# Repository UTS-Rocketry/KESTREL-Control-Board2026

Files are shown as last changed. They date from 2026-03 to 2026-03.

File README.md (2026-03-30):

# CAS Interface Board 2026



Control Actuation System (CAS) Interface Board for the UTS Rocketry avionics stack.

This board provides closed-loop control for the airbrake and parafoil control systems, along with sensor interfaces and onboard data logging. The design is based on the STM32F405RGT6 microcontroller and integrates inertial sensing, actuator control, and non-volatile storage.

The CAS board is intended to operate as part of the UTS Rocketry flight avionics architecture.

---

## Overview

The CAS Interface Board is responsible for:

- Airbrake deployment control
- Roll stabilisation control
- Sensor acquisition
- Data logging
- Actuator interfacing

Closed-loop control is performed onboard using IMU, barometric sensor, and GPS measurements.

---

## Hardware

### Microcontroller

STM32F405RGT6

- ARM Cortex-M4F
- 168 MHz
- Hardware floating point
- 1 MB Flash
- 192 KB RAM

---

### Sensors

#### IMU

LSM6DS3TR-C

Interface:

- SPI (4-wire)

Signals:

- SCK
- MOSI
- MISO
- CS
- DRDY Interrupt

Power:

- 3.3 V

---

#### Barometer

Interface:

- I2C

Signals:

- SCL
- SDA

Power:

- 3.3 V

---

### Storage

#### MicroSD Card

Interface:

- SPI

Signals:

- SCK
- MOSI
- MISO
- CS

Purpose:

- Flight data logging

---

### Actuator Interfaces

#### Servo Outputs

- Airbrake Servo
- Roll Control Servo

Control Method:

- Timer PWM outputs

Power:

- Dedicated 5 V servo rail

Signal Voltage:

- 3.3 V logic

---

## Control System

### Airbrake Control

The CAS system predicts apogee using altitude and velocity estimates derived from sensor measurements.

Airbrake deployment is adjusted to reach the target apogee.

Inputs:

- Barometer altitude
- Estimated vertical velocity

Outputs:

- Airbrake servo PWM

## Firmware

Development tools:

- STM32CubeMX
- STM32CubeIDE
- ST-Link

Features:

- SPI IMU driver
- I2C barometer driver
- PWM servo control
- SD card logging
- Flash logging
- Interrupt-driven sensor acquisition

---

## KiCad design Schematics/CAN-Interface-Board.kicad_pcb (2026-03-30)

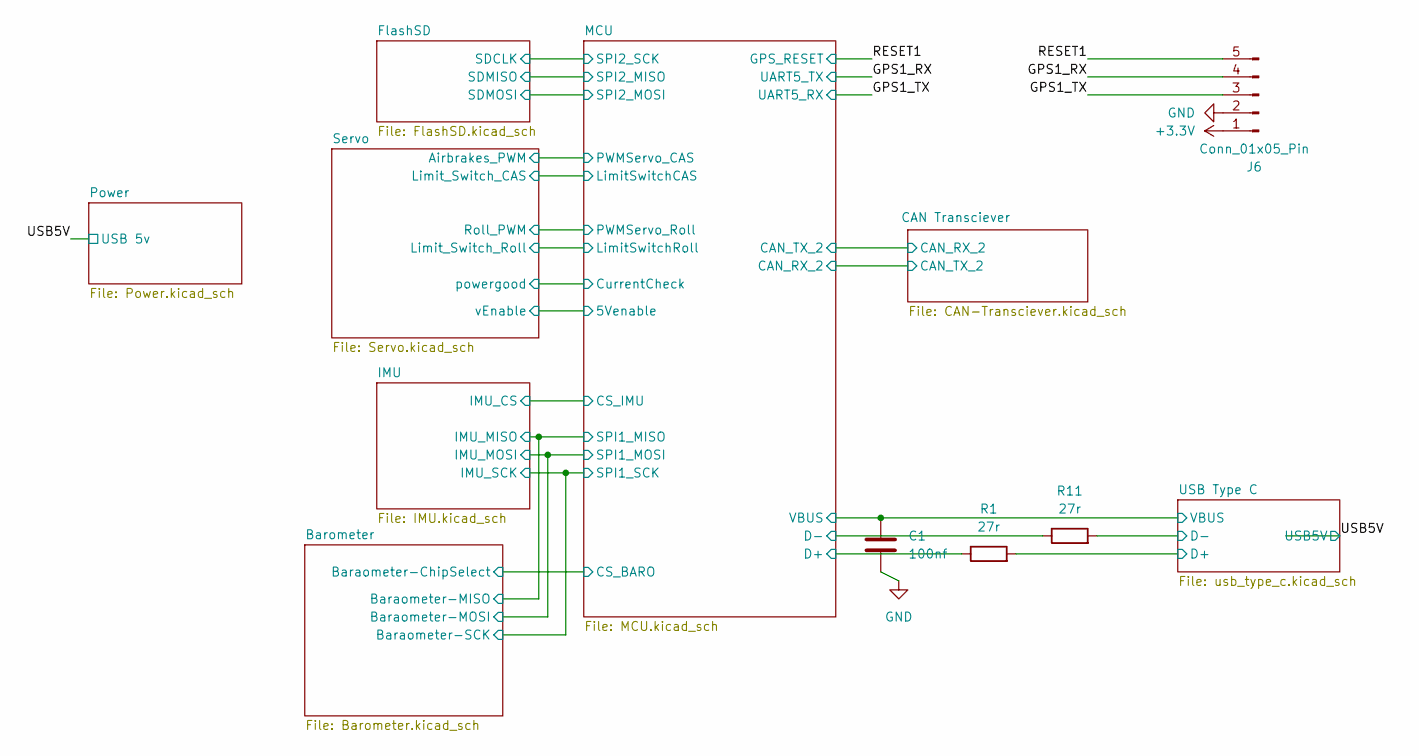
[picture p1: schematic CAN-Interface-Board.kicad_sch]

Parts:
C1: 100nf; C_0805_2012Metric_Pad1.18x1.45mm_HandSolder; LCSC C49678
J6: Conn_01x05_Pin; JST_XH_B5B-XH-A_1x05_P2.50mm_Vertical; LCSC C157991
R1, R11: 27r; R_0805_2012Metric_Pad1.20x1.40mm_HandSolder; LCSC C17594

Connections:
+3.3V: J6.1; also elsewhere on the board
/GPS1_RX: J6.4; also elsewhere on the board
/GPS1_TX: J6.3; also elsewhere on the board
/MCU/D+: R1.1; also elsewhere on the board
/MCU/D-: R11.1; also elsewhere on the board
/RESET1: J6.5; also elsewhere on the board
/USB5V: C1.1; also elsewhere on the board
/USB Type C/D+: R1.2; also elsewhere on the board
/USB Type C/D-: R11.2; also elsewhere on the board
GND: C1.2, J6.2; also elsewhere on the board

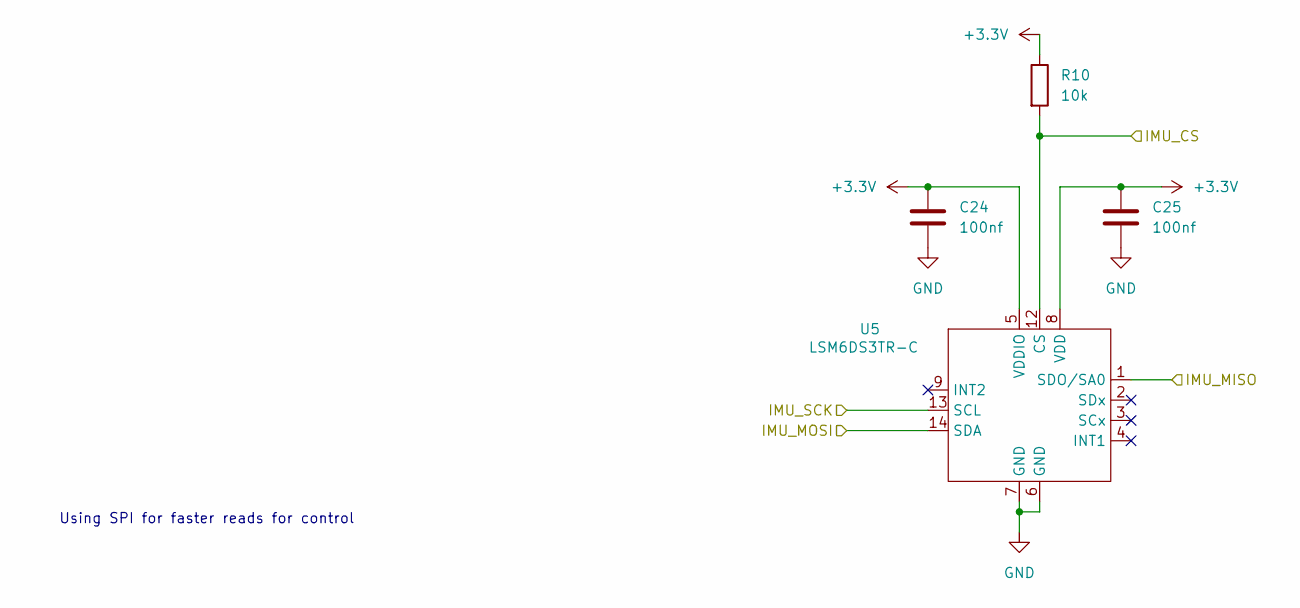
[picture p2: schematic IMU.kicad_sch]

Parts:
C24, C25: 100nf; C_0805_2012Metric_Pad1.18x1.45mm_HandSolder; LCSC Part C49678
R10: 10k; R_0805_2012Metric_Pad1.20x1.40mm_HandSolder; LCSC C84376
U5: LSM6DS3TR-C; LGA-14-2.5X3MM; LCSC Part C967633

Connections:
+3.3V: C24.1, C25.1, R10.1, U5.5 (VDDIO), U5.8 (VDD); also elsewhere on the board
/Barometer/Baraometer-MISO: U5.1 (SDO/SA0); also elsewhere on the board
/Barometer/Baraometer-MOSI: U5.14 (SDA); also elsewhere on the board
/Barometer/Baraometer-SCK: U5.13 (SCL); also elsewhere on the board
/IMU/IMU_CS: R10.2, U5.12 (CS); also elsewhere on the board
GND: C24.2, C25.2, U5.6 (GND), U5.7 (GND); also elsewhere on the board

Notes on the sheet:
Using SPI for faster reads for control

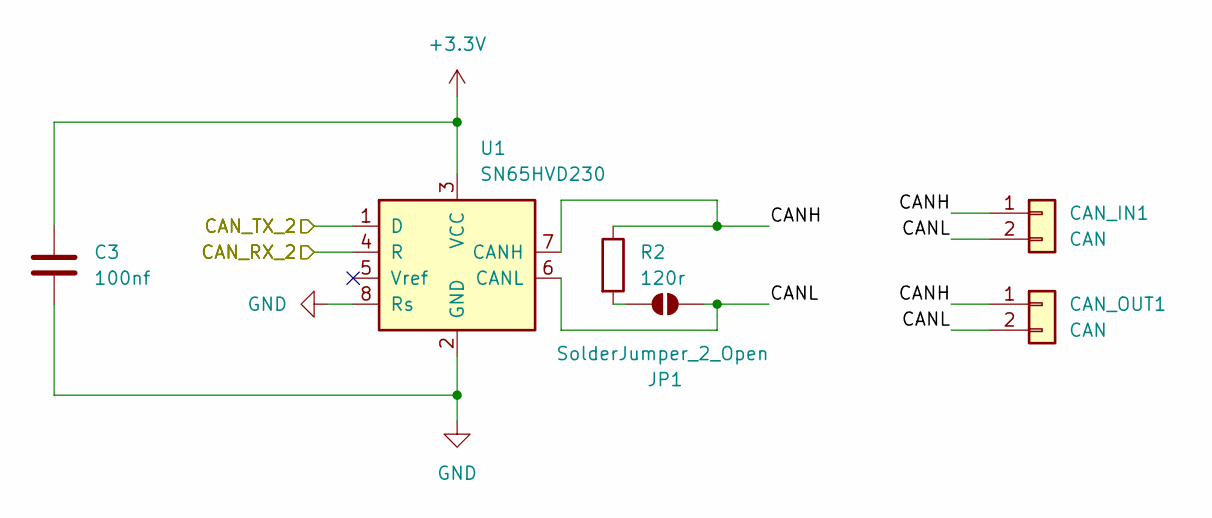
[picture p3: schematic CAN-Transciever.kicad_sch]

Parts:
C3: 100nf; C_0805_2012Metric_Pad1.18x1.45mm_HandSolder; LCSC Part C49678
CAN_IN1: CAN; MOLEX_26013114; LCSC Part C17644051
CAN_OUT1: CAN; MOLEX_26013114; LCSC Part C17644051
JP1: SolderJumper_2_Open; SolderJumper-2_P1.3mm_Open_TrianglePad1.0x1.5mm; LCSC C474893
R2: 120r; R_0805_2012Metric_Pad1.20x1.40mm_HandSolder; LCSC Part C269726
U1: SN65HVD230; SOIC-8_3.9x4.9mm_P1.27mm; LCSC Part C1543812

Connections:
+3.3V: C3.1, U1.3 (VCC); also elsewhere on the board
/CAN Transciever/CANH: CAN_IN1.1, CAN_OUT1.1, R2.1, U1.7 (CANH)
/CAN Transciever/CANL: CAN_IN1.2, CAN_OUT1.2, JP1.2 (B), U1.6 (CANL)
/CAN Transciever/CAN_RX_2: U1.4 (R); also elsewhere on the board
/CAN Transciever/CAN_TX_2: U1.1 (D); also elsewhere on the board
GND: C3.2, U1.2 (GND), U1.8 (Rs); also elsewhere on the board
unnamed: JP1.1 (A), R2.2

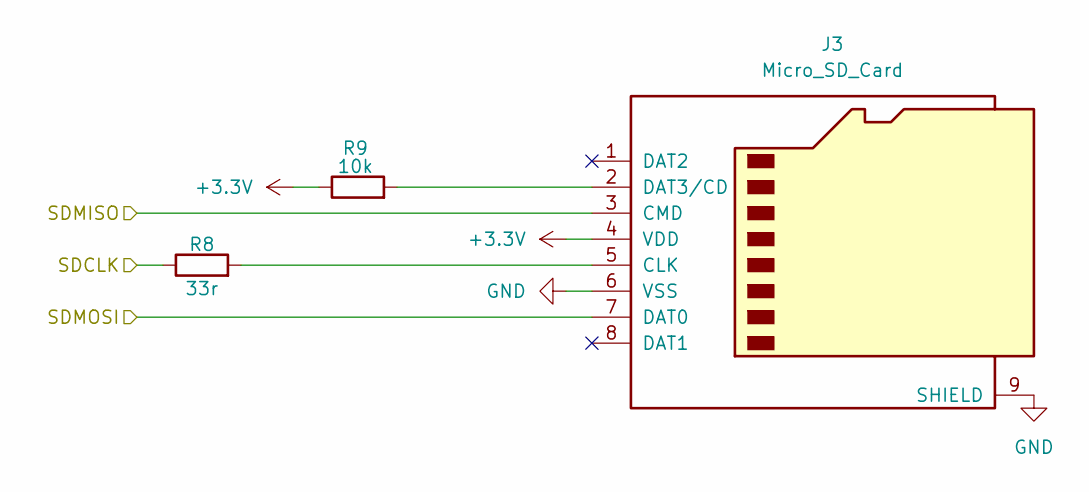
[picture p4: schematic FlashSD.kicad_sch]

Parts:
J3: Micro_SD_Card; microSD_HC_Molex_47219-2001; LCSC Part C164170
R8: 33r; R_0805_2012Metric_Pad1.20x1.40mm_HandSolder; LCSC Part C17557
R9: 10k; R_0805_2012Metric_Pad1.20x1.40mm_HandSolder; LCSC Part C84376

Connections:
+3.3V: J3.4 (VDD), R9.1; also elsewhere on the board
/FlashSD/SDCLK: R8.1; also elsewhere on the board
/FlashSD/SDMISO: J3.3 (CMD); also elsewhere on the board
/FlashSD/SDMOSI: J3.7 (DAT0); also elsewhere on the board
GND: J3.6 (VSS), J3.9 (SHIELD); also elsewhere on the board
unnamed: J3.5 (CLK), R8.2
unnamed: J3.2 (DAT3/CD), R9.2

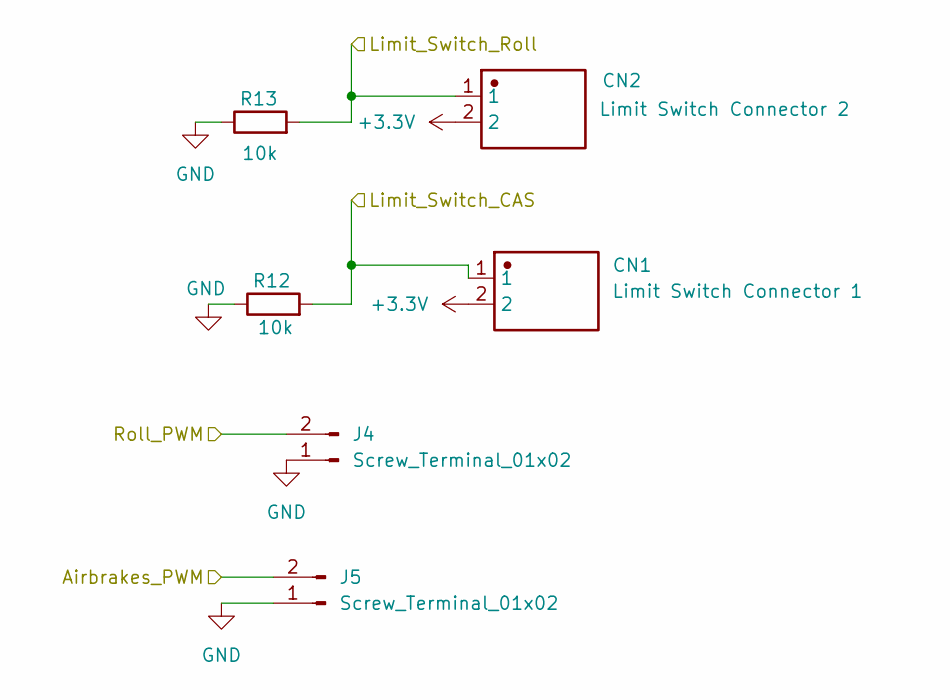
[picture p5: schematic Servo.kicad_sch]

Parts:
CN1: Limit Switch Connector 1; JST_EH_B2B-EH-A_1x02_P2.50mm_Vertical; LCSC Part C158012
CN2: Limit Switch Connector 2; JST_EH_B2B-EH-A_1x02_P2.50mm_Vertical; LCSC Part C158012
J4, J5: Screw_Terminal_01x02; JST_EH_B2B-EH-A_1x02_P2.50mm_Vertical; LCSC C158012
R12, R13: 10k; R_0805_2012Metric_Pad1.20x1.40mm_HandSolder; LCSC Part C4277843

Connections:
+3.3V: CN1.2, CN2.2; also elsewhere on the board
/MCU/LimitSwitchCAS: CN1.1, R12.2; also elsewhere on the board
/MCU/LimitSwitchRoll: CN2.1, R13.2; also elsewhere on the board
/MCU/PWMServo_CAS: J5.2; also elsewhere on the board
/MCU/PWMServo_Roll: J4.2; also elsewhere on the board
GND: J4.1, J5.1, R12.1, R13.1; also elsewhere on the board

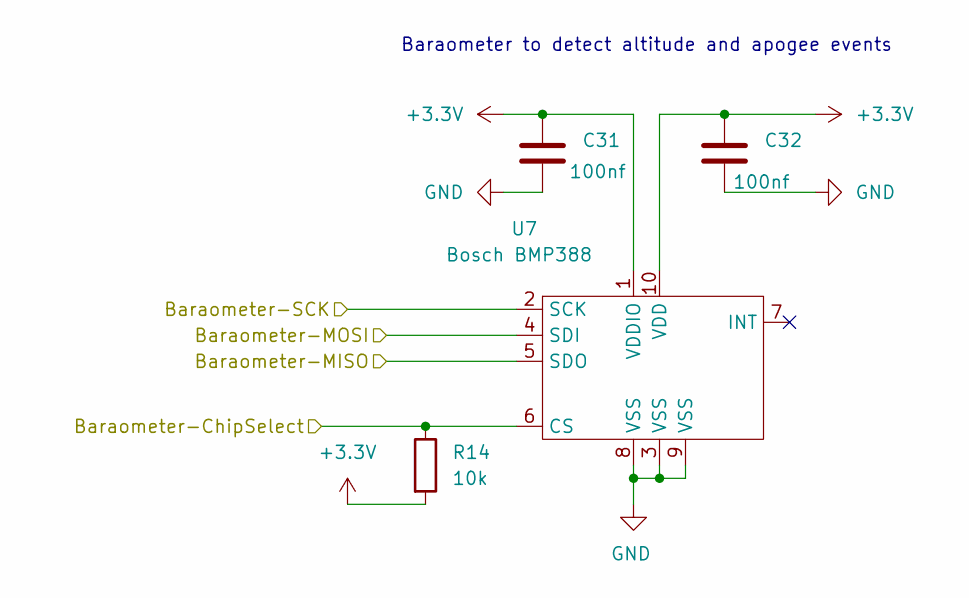
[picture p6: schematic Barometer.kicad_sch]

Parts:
C31, C32: 100nf; C_0805_2012Metric_Pad1.18x1.45mm_HandSolder; LCSC C49678
R14: 10k; R_0805_2012Metric_Pad1.20x1.40mm_HandSolder; LCSC C84376
U7: Bosch BMP388; PQFN50P200X200X80-10N; LCSC C779278

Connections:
+3.3V: C31.1, C32.1, R14.2, U7.1 (VDDIO), U7.10 (VDD); also elsewhere on the board
/Barometer/Baraometer-ChipSelect: R14.1, U7.6 (CS); also elsewhere on the board
/Barometer/Baraometer-MISO: U7.5 (SDO); also elsewhere on the board
/Barometer/Baraometer-MOSI: U7.4 (SDI); also elsewhere on the board
/Barometer/Baraometer-SCK: U7.2 (SCK); also elsewhere on the board
GND: C31.2, C32.2, U7.3 (VSS), U7.8 (VSS), U7.9 (VSS); also elsewhere on the board

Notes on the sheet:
Baraometer to detect altitude and apogee events

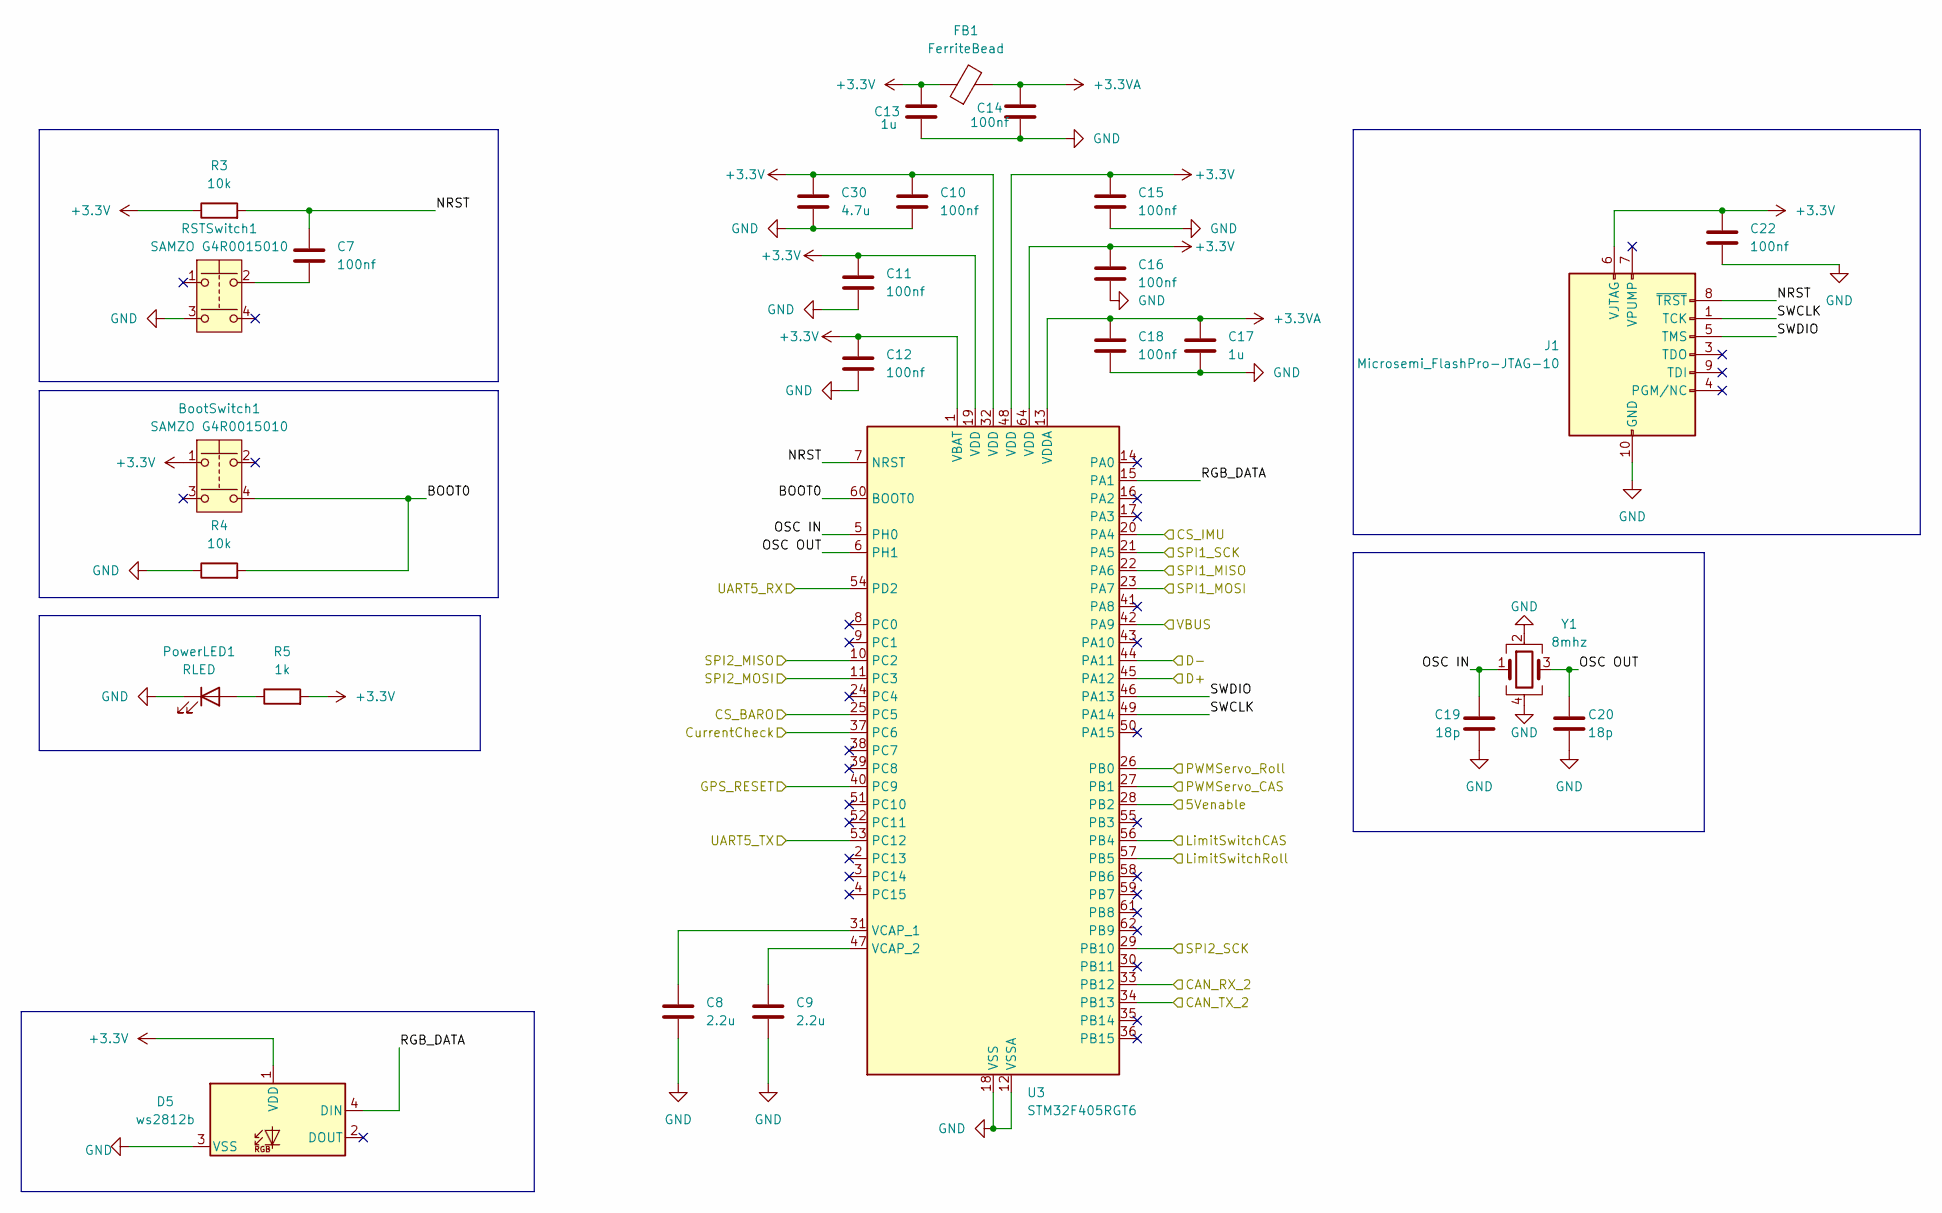
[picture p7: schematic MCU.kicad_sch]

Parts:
BootSwitch1: SAMZO G4R0015010; LCSC Part C49393646
C7: 100nf; C_0805_2012Metric_Pad1.18x1.45mm_HandSolder; LCSC Part C49678
C8, C9: 2.2u; C_0805_2012Metric_Pad1.18x1.45mm_HandSolder; LCSC C19110
C10, C11, C12, C14, C15, C16, C18, C22: 100nf; C_0805_2012Metric_Pad1.18x1.45mm_HandSolder; LCSC C49678
C13, C17: 1u; C_0805_2012Metric_Pad1.18x1.45mm_HandSolder; LCSC C28323
C19, C20: 18p; C_0805_2012Metric_Pad1.18x1.45mm_HandSolder; LCSC Part C170109
C30: 4.7u; C_0805_2012Metric_Pad1.18x1.45mm_HandSolder; LCSC C98192
D5: ws2812b; LED_WS2812B_PLCC4_5.0x5.0mm_P3.2mm; LCSC C2761795
FB1: FerriteBead; R_0805_2012Metric_Pad1.20x1.40mm_HandSolder; LCSC C85840
J1: Microsemi_FlashPro-JTAG-10; PinHeader_2x05_P1.27mm_Vertical; LCSC Part C22438120
PowerLED1: RLED; LED_0603_1608Metric_Pad1.05x0.95mm_HandSolder; LCSC Part C965799
R3: 10k; R_0805_2012Metric_Pad1.20x1.40mm_HandSolder; LCSC Part C84376
R4: 10k; R_0805_2012Metric_Pad1.20x1.40mm_HandSolder; LCSC Part C96346
R5: 1k; R_0805_2012Metric_Pad1.20x1.40mm_HandSolder; LCSC Part C95781
RSTSwitch1: SAMZO G4R0015010; LCSC Part C49393646
U3: STM32F405RGT6; LQFP-64_10x10mm_P0.5mm; LCSC C15742
Y1: 8mhz; Crystal_SMD_3225-4Pin_3.2x2.5mm_HandSoldering; LCSC Part C19723344

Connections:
+3.3V: BootSwitch1.1, C10.1, C11.1, C12.1, C13.2, C15.1, C16.1, C22.1, C30.1, D5.1 (VDD), FB1.1, J1.6 (VJTAG), R3.1, R5.2, U3.1 (VBAT), U3.19 (VDD), U3.32 (VDD), U3.48 (VDD), U3.64 (VDD); also elsewhere on the board
+3.3VA: C14.2, C17.1, C18.1, FB1.2, U3.13 (VDDA)
/Barometer/Baraometer-ChipSelect: U3.25 (PC5); also elsewhere on the board
/Barometer/Baraometer-MISO: U3.22 (PA6); also elsewhere on the board
/Barometer/Baraometer-MOSI: U3.23 (PA7); also elsewhere on the board
/Barometer/Baraometer-SCK: U3.21 (PA5); also elsewhere on the board
/CAN Transciever/CAN_RX_2: U3.34 (PB13); also elsewhere on the board
/CAN Transciever/CAN_TX_2: U3.33 (PB12); also elsewhere on the board
/FlashSD/SDCLK: U3.29 (PB10); also elsewhere on the board
/FlashSD/SDMISO: U3.10 (PC2); also elsewhere on the board
/FlashSD/SDMOSI: U3.11 (PC3); also elsewhere on the board
/GPS1_RX: U3.53 (PC12); also elsewhere on the board
/GPS1_TX: U3.54 (PD2); also elsewhere on the board
/IMU/IMU_CS: U3.20 (PA4); also elsewhere on the board
/MCU/5Venable: U3.28 (PB2)
/MCU/BOOT0: BootSwitch1.4, R4.2, U3.60 (BOOT0)
/MCU/CurrentCheck: U3.37 (PC6)
/MCU/D+: U3.45 (PA12); also elsewhere on the board
/MCU/D-: U3.44 (PA11); also elsewhere on the board
/MCU/LimitSwitchCAS: U3.56 (PB4); also elsewhere on the board
/MCU/LimitSwitchRoll: U3.57 (PB5); also elsewhere on the board
/MCU/NRST: C7.1, J1.8 (~TRST), R3.2, U3.7 (NRST)
/MCU/OSC IN: C19.1, U3.5 (PH0), Y1.1
/MCU/OSC OUT: C20.1, U3.6 (PH1), Y1.3
/MCU/PWMServo_CAS: U3.27 (PB1); also elsewhere on the board
/MCU/PWMServo_Roll: U3.26 (PB0); also elsewhere on the board
/MCU/RGB_DATA: D5.4 (DIN), U3.15 (PA1)
/MCU/SWCLK: J1.1 (TCK), U3.49 (PA14)
/MCU/SWDIO: J1.5 (TMS), U3.46 (PA13)
/RESET1: U3.40 (PC9); also elsewhere on the board
/USB5V: U3.42 (PA9); also elsewhere on the board
GND: C8.2, C9.2, C10.2, C11.2, C12.2, C13.1, C14.1, C15.2, C16.2, C17.2, C18.2, C19.2, C20.2, C22.2, C30.2, D5.3 (VSS), J1.2 (GND), J1.10 (GND), PowerLED1.1 (K), R4.1, RSTSwitch1.3, U3.12 (VSSA), U3.18 (VSS), U3.63 (VSS), Y1.2, Y1.4; also elsewhere on the board
unnamed: C7.2, RSTSwitch1.2
unnamed: PowerLED1.2 (A), R5.1
unnamed: C8.1, U3.31 (VCAP_1)
unnamed: C9.1, U3.47 (VCAP_2)

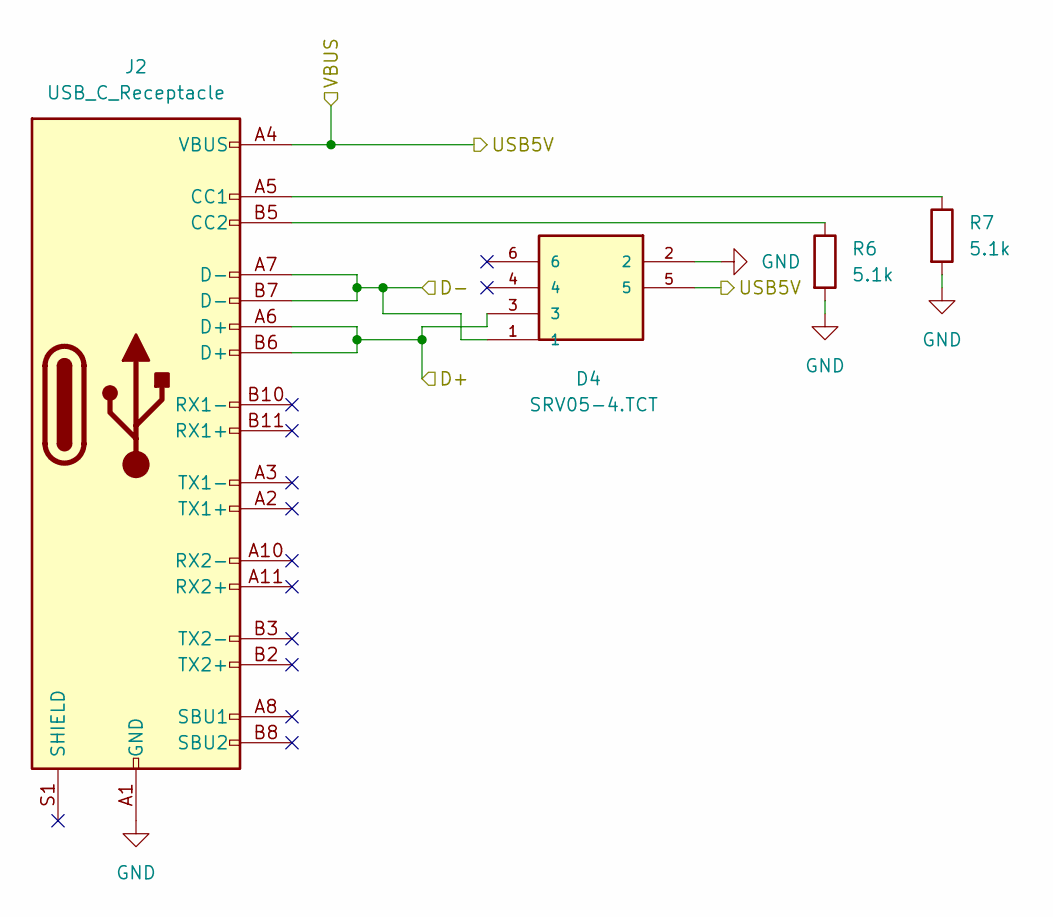
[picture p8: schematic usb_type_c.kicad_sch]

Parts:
D4: SRV05-4.TCT; SOT-23-6; MOUSER_PART_NUMBER 947-SRV05-4.TCT
J2: USB_C_Receptacle; USB_C_Receptacle_HRO_TYPE-C-31-M-12; LCSC C49566391
R6, R7: 5.1k; R_0805_2012Metric_Pad1.20x1.40mm_HandSolder; LCSC C27834

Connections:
/USB5V: D4.5, J2.A4 (VBUS), J2.A9 (VBUS), J2.B4 (VBUS), J2.B9 (VBUS); also elsewhere on the board
/USB Type C/D+: D4.3, J2.A6 (D+), J2.B6 (D+); also elsewhere on the board
/USB Type C/D-: D4.1, J2.A7 (D-), J2.B7 (D-); also elsewhere on the board
GND: D4.2, J2.A1 (GND), J2.A12 (GND), J2.B1 (GND), J2.B12 (GND), R6.2, R7.2; also elsewhere on the board
unnamed: J2.A5 (CC1), R7.1
unnamed: J2.B5 (CC2), R6.1

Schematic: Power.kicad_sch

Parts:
C4: 1u; C_0805_2012Metric_Pad1.18x1.45mm_HandSolder; LCSC Part C28323
C5: 4.7u; C_0805_2012Metric_Pad1.18x1.45mm_HandSolder; LCSC Part C98192
D1, D2: D_Schottky; D_2114_3652Metric; LCSC C113936
PowerIn1: 2 pin Molex; MOLEX_26013114; LCSC C17644051
U2: LDL1117-3.3; SOT230P700X180-4N; LCSC C435835

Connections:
+3.3V: C5.1, U2.3 (Vout), U2.4 (Vout); also elsewhere on the board
+BATT: D1.2 (A), PowerIn1.1
/USB5V: D2.2 (A); also elsewhere on the board
GND: C4.2, C5.2, PowerIn1.2, U2.2 (GND); also elsewhere on the board
unnamed: C4.1, D1.1 (K), D2.1 (K), U2.1 (Vin)

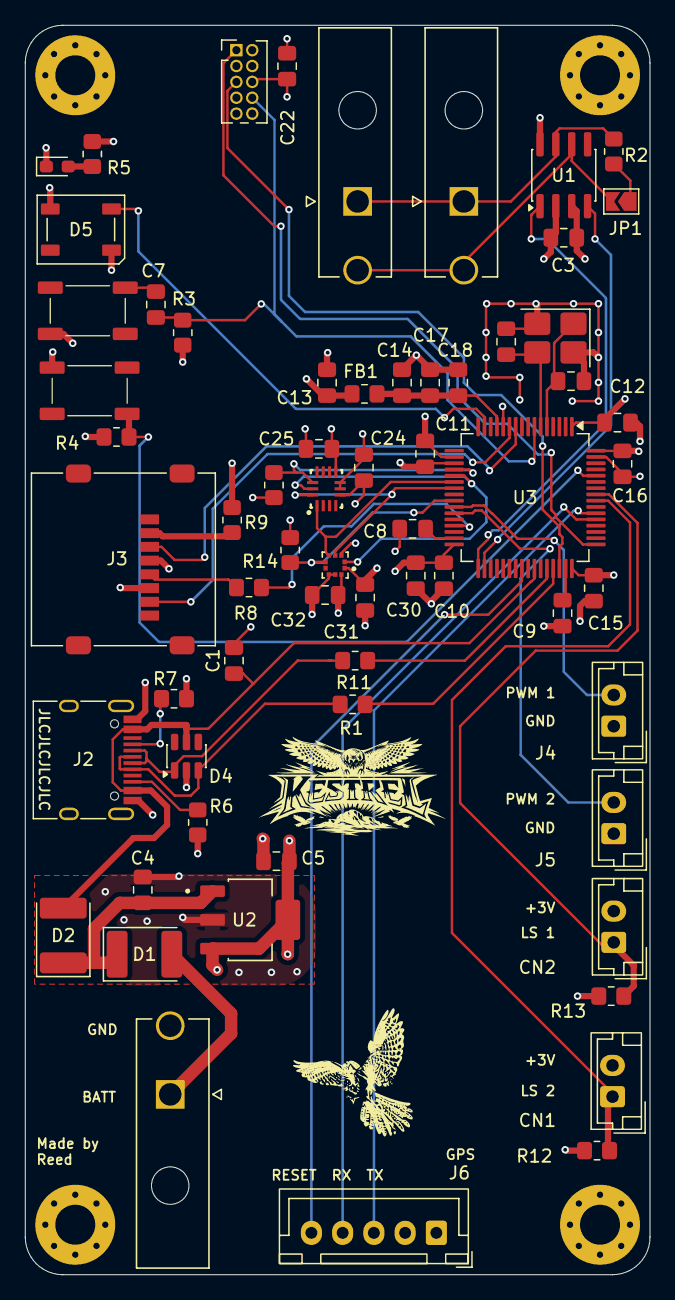
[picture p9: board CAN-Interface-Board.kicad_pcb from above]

Board: 4 copper layers, 50.0 x 100.0 mm, 64 parts (0 on the bottom side), 45 nets.

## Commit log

2026-03-16 started new design with esp32
    [Barometer.kicad_sch, CAN-Interface-Board.kicad_pcb, CAN-Interface-Board.kicad_sch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]
2026-03-17 added esp32 for uart to tune control systems from a web browser app
    [CAN-Interface-Board.kicad_pcb, CAN-Interface-Board.kicad_sch, ESP32-C3-Mini.kicad_sch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]
2026-03-17 finished first layout and routing
    [CAN-Interface-Board.kicad_pcb, ESP32-C3-Mini.kicad_sch, Servo.kicad_sch]
2026-03-17 clean up of routing
    [CAN-Interface-Board.kicad_pcb, CAN-Interface-Board.kicad_sch, CAN-Transciever.kicad_sch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]
2026-03-24 updated board waiting on review
    [Barometer.kicad_sch, CAN-Interface-Board.kicad_pcb, CAN-Interface-Board.kicad_sch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]
2026-03-25 Updating to KiCad 10.0
    [CAN-Interface-Board.kicad_pcb, MCU.kicad_sch]
2026-03-27 removed esp32 to seperate board, added gps breakout, pending final review for purchase
    [CAN-Interface-Board.kicad_pcb, CAN-Interface-Board.kicad_sch, MCU.kicad_sch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]
2026-03-27 finished waiting for review
    [CAN-Interface-Board.kicad_pcb, CAN-Interface-Board.kicad_sch, Servo.kicad_sch]
2026-03-30 final draft, in JLPCB cart
    [Barometer.kicad_sch, CAN-Interface-Board.kicad_pcb, CAN-Interface-Board.kicad_sch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]
